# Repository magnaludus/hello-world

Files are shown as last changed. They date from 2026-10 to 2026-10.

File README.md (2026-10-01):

# U1 Breath

A chamber heater and HEPA + activated-carbon filter unit for the **Snapmaker U1**, in the
same class and the same 273 x 175 x 55 mm envelope as the BIQU Panda Breath.

- 300 W 120 V PTC heater, 7530 blower, two 80x80 filter bays (four 80x40x15 HEPA cells plus
  pellet carbon cartridges)
- Own mains power supply; plugs into a wall outlet, works with the printer off
- WiFi web UI, preheat, auto, filament-drying and filter-only modes
- A thermistor stuck under the heated bed turns the unit on and off by itself
  (default: heat when bed >= 90 C, stop below 70 C, filter-only above 45 C)
- Klipper integration with **zero printer-side code**: the firmware speaks the open
  [DragonBreath](https://github.com/plastikman/DragonBreath) REST API, which the
  [paxx12 U1 Extended Firmware](https://github.com/paxx12-snapmaker-u1/SnapmakerU1-Extended-Firmware)
  already drives as a `heater_generic`, so `M141` / `M191` from OrcaSlicer just work
- Mounts inside the chamber on the rear wall, printed in ASA/ABS with M3 heat-set inserts;
  only the heater duct liner is aluminum

## Repository map

| Path | What it is |
|---|---|
| `docs/design.md` | Architecture, airflow, thermal and dimension budgets, safety model |
| `docs/bom.md` | Bill of materials with ratings and example parts |
| `docs/wiring.md` | Wiring diagram, connector pinout, mains safety notes |
| `docs/assembly.md` | Print settings, inserts, step-by-step assembly, liner folding |
| `docs/bringup.md` | First-power checklist, foldback calibration, Klipper enable steps |
| `docs/measurements.md` | The handful of measurements only the owner can take |
| `cad/` | CadQuery parametric model; `python cad/build.py` exports STL, STEP, DXF, SVG |
| `firmware/` | DragonBreath fork with the `u1breath` board profile |
| `klipper/` | Optional macros for the paxx12 `klipper_includes` feature |

## Quick start

1. Read `docs/measurements.md` and fill in `cad/u1breath/params.py`.
2. `pip install cadquery` then `python cad/build.py` to get the printable parts in `cad/out/`.
3. Order the parts in `docs/bom.md`.
4. Build and flash the firmware (`firmware/README.md`), join it to WiFi, give it a static DHCP lease.
5. Assemble (`docs/assembly.md`), then follow `docs/bringup.md` before the first heated print.

## Safety

This project switches 120 V mains inside a printer enclosure. The heater path has three
independent cut-offs (bimetal thermal protector bundled with the PTC element, a one-shot
thermal fuse on the duct liner, and the firmware's latching over-temperature logic), but
the build is only as safe as its wiring. Use the cord, fuse, and crimps specified in the BOM,
keep every mains conductor inside the electronics bay, and never run the heater with the
blower disconnected.

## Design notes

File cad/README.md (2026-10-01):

# U1 Breath CAD

Parametric CadQuery model of the U1 Breath chamber heater + HEPA/carbon filter
unit for the Snapmaker U1.  Overall 172 (X) x 54 (Y) x 273 (Z) mm, three stacked
sections serviced from the front, all plastic parts in ASA with M3 heat-set
inserts, only the heater duct liner in 1 mm aluminium.

## Run

```sh
pip install cadquery pytest          # CadQuery 2.8 or newer
python3 cad/build.py                 # everything, about a minute
python3 cad/build.py mid_body        # one part (STL + STEP only)
python3 -m pytest cad/tests -q       # envelope, build-volume and hot-gap checks
```

Outputs land in `cad/out/` (git-ignored):

| Path | Content |
|---|---|
| `out/stl/<part>.stl`, `out/step/<part>.step` | every part, in its assembled position (bay 0 for the per-bay parts) |
| `out/dxf/heater_liner_flat.dxf` | liner flat pattern, layers `OUTLINE`, `HOLES`, `BEND` |
| `out/layout.svg` | front and side views of the assembly |
| `out/exploded.svg` | exploded isometric view |

Every dimension is a named constant in `cad/u1breath/params.py`; change it there
and rebuild.  Fill in the values from `docs/measurements.md` first (`MOUNT_HOLES`,
`PTC_L/D/H`, `CARBON_MESH_PITCH`).

## Coordinate frame

`Y = 0` is the back face on the printer's rear wall, `+Y` toward the chamber,
`Z = 0` the bottom, air flows up.  The frame is right-handed, so `+X` runs to your
left when you face the unit from inside the chamber (and to the right when the
unit lies on its back, as the parts are printed).  Low X holds the blower, high X
the electronics bay.

## Parts

| Part | Qty | What it is | Print orientation |
|---|---|---|---|
| `back_plate_lower`, `back_plate_upper` | 1 + 1 | 3 mm plate on the rear wall, split at Z 140 with a 10 mm half-thickness lap joint (the full 273 mm plate does not fit the 256 mm bed). Carries the 20 mm mounting grid (4.5 mm, X 10 / 162), six countersunk M4 holes, the M3 clearance holes for the three bodies, the blower's 4 x M4 holes and the standoff bosses for the electronics. | flat, back face (Y = 0) down; the bosses point up |
| `back_plate` | ref. | the same plate in one piece, for printers with a taller bed | flat |
| `filter_bay_body` | 1 | Z 0..110. Two 80 x 80 bay tunnels; from the front: grille, carbon cartridge slot (15), HEPA slot (2 cells 80 x 40 x 15 stacked), retainer frame (3), 12 mm plenum. The plenum fills the whole cavity behind the tunnels and leaves through the 85 x 30 mm roof opening into the blower cavity. | front face (Y = 53) down, open back up; the boss blocks print as columns |
| `intake_grille` | 2 | 3 mm slotted grille (5 mm slots, 2 mm bars), snaps into the bore with two 1 mm nubs; sits 2 mm behind the front face | flat, front down |
| `carbon_cartridge` | 2 | 79.5 x 79.5 x 13 tray with a 2 mm square-mesh back face and two M2 insert bosses; fill with pellet carbon | mesh face down |
| `carbon_cartridge_lid` | 2 | 79.5 x 79.5 x 2 mesh lid, 2 x M2 button screws | flat |
| `hepa_retainer` | 2 | 3 mm open frame with a centre bar between the two cells; goes in first and rests on a 1.5 mm lip at the back of the bore, the HEPA cells drop in after it | flat |
| `mid_body` | 1 | Z 110..195. Sealed blower cavity (low X, fed through the floor opening from the filter plenum; the 7530 lies flat, inlet toward +Y, outlet through the roof opening into the heater shell) and the electronics bay (high X) with four M3 cover bosses and the 12.5 mm PG7 cord-grip hole in the side wall | front face (Y = 48) down, open back up |
| `electronics_cover` | 1 | 3 mm cover with the 10 x 10 LED window and the 8 x 6 JST-XH bed-probe slot; 4 x M3 button screws | flat, front down |
| `heater_shell` | 1 | Z 195..273. ASA box around the liner keeping an 8 mm air gap on every side (2 mm side walls, see below), floor opening above the blower outlet, four bosses behind the front frame for the liner screws | front face (Y = 52) down, open back up |
| `heater_liner` | ref. | folded 1 mm aluminium box (back, top, bottom, two sides; outward 16 mm lips on top and bottom; 10 mm corner tabs) plus the flat slotted front plate 172 x 78 (four rows of 3 x 132 mm slots). Cut both from the DXF. Holes: inlet slot in the bottom wall over the plenum, M3 for the bimetal thermal protector on the top face, M3 for the ring-lug NTC on the high-X side face, 8 mm lead grommet on the low-X side face, four M3 screw holes in the lips and the plate. | not printed |
| `blower_keepout`, `electronics_keepouts`, `ptc_keepout` | ref. | keep-out boxes used by the collision tests | not printed |

Screws: all section bodies screw from behind the back plate into M3 inserts in
the bodies (four per section); the electronics cover and the liner plate screw
from the front.  Inserts: M3 x 5.7 (4.0 mm hole, 6 mm bosses), M2 for the
cartridge lids.  Clearances: 0.3 mm on sliding fits (filters, cartridge,
cover), 0.15 mm on the grille snap nubs.

## Airflow

Grille -> carbon cartridge -> two HEPA cells -> retainer frame -> 12 mm plenum ->
up through the roof opening of the filter bay into the blower cavity -> blower
inlet (+Y face) -> outlet through the mid-body roof and heater-shell floor into
the cold jacket around the liner -> slot in the liner's bottom wall into the 8 mm
plenum behind the PTC -> through the fins toward +Y -> out through the slotted
front plate.  The jacket air keeps the shell cool; the liner never touches plastic.

## Depth budget (Y)

| Section | Stack | Total |
|---|---|---|
| filter bay | 3 plate + 12 plenum + 3 retainer + 15 HEPA + 15 carbon + 3 wall + 2 lip | 53 |
| mid | 3 plate + 30 blower + 12 inlet plenum + 3 wall | 48 |
| heater | 3 plate + 8 gap + 1 liner + 8 plenum + 32 PTC + 1 lips + 1 slotted plate | 54 |

`HEATER_DEPTH` (54) is asserted <= 55 by the tests.

## Tests (`cad/tests/test_envelope.py`)

- every part is a single solid
- the assembled unit is within 273 x 175 x 55 mm (H x W x D) and nothing is behind Y = 0
- every printed part fits a 256 mm cube
- no plastic part intrudes into the liner's inner volume grown by `HOT_GAP` (8 mm) within the heater section
- the PTC, blower and electronics keep-outs collide with nothing

## Design notes / deviations from the brief

- The heater shell's side walls are 2 mm (not 3): 150 mm element + 2 x 1 mm clearance + 2 x 8 mm gap + 2 x 2 mm wall is exactly 172 mm.
- The liner has no printed duct from the blower: the whole shell cavity is the cold-side plenum and the liner takes air through a slot in its bottom wall.  A printed duct would have to touch the liner.
- The slotted outlet is a separate flat plate (second outline in the DXF), screwed through the liner's top/bottom lips into the shell; it adds 1 mm of depth (54 total).  Outlet slots are straight, not angled.
- The HEPA retainer frame adds 3 mm to the filter bay depth (53 instead of 50) because it cannot live inside the 15 mm HEPA slot while the cells fill the full 80 x 80 bore.
- The back plate is printed in two halves with a lap joint.
- The electronics standoff bosses are on the back plate (prints flat), not inside the mid body, so the mid body prints front-face-down without supports.
- The bosses that hold the bodies to the back plate are full-depth columns on the walls (filter bay: blocks in the strips above and below the bay tunnels) so that they print without overhangs; their positions avoid the 20 mm mounting grid.
- `outlet_shroud` was skipped (any trim in front of the plate would exceed the 55 mm depth).

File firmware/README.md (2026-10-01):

# U1 Breath firmware

The firmware is [DragonBreath](https://github.com/plastikman/DragonBreath) with a
`u1breath` board profile (see `UPSTREAM.md` for exactly what differs). You get the
upstream web UI, captive-portal WiFi setup, OTA, Moonraker client, lease/heartbeat
safety model, drying mode, and the paxx12 U1 Extended Firmware integration, plus
the local bed-probe AUTO trigger and the DC blower / WS2812 / 100K NTC hardware.

## Build

Requires ESP-IDF **v5.3.2 or newer** (CI uses v5.3.5). From `firmware/dragonbreath/`:

```bash
. ~/esp/esp-idf/export.sh
idf.py -B build-u1breath \
  -DSDKCONFIG_DEFAULTS="sdkconfig.defaults;sdkconfig.u1breath" build
```

The board is selected by `sdkconfig.u1breath` (`CONFIG_PB_BOARD_U1BREATH=y`). A
plain `idf.py build` still produces the stock Panda Breath image; never flash that
one onto a U1 Breath board.

Optional: copy `main/dev_config.h.example` to `main/dev_config.h` with your WiFi
SSID/password and the printer's Moonraker IP to seed them at first boot. Otherwise
the device starts a `DragonBreath-xxxx` access point and you set them in the portal.

## Flash

The XIAO ESP32-C3's own USB-C port is the flashing and console port (native USB
Serial/JTAG). Hold BOOT while plugging in only if the chip refuses to enter the
bootloader on its own.

```bash
idf.py -B build-u1breath -p /dev/ttyACM0 flash monitor
```

Later updates: use the web UI's firmware update page with
`build-u1breath/dragonbreath.bin` (OTA with automatic rollback if the new image
does not come up healthy).

## First boot

1. Join the `DragonBreath-xxxx` AP, open `http://192.168.4.1`, enter WiFi and the
   printer's Moonraker address. Control source: **Klipper**.
2. Give the unit a **static DHCP lease** on your router. The paxx12 integration
   needs a stable IP.
3. Open `http://<unit-ip>/`. Settings to check on a U1 Breath:

| Setting | Default | Meaning |
|---|---|---|
| `probe_auto` | on | AUTO may heat from the bed probe |
| `probe_on` | 90 C | bed probe at or above this engages heat (in AUTO) |
| `probe_off` | 70 C | bed probe below this releases heat (at least 5 C under `probe_on`) |
| `filter_auto` / `filter_temp` | on / 45 C | blower-only filtration when the bed (probe or printer setpoint) reaches this |
| `max` | 70 C | chamber set-point ceiling (absolute firmware cap, not raisable) |
| `fb_cut` | auto (102 C) | duct-sensor soft foldback; set from bring-up measurements, see `docs/bringup.md` |

The status pixel: dim white idle, green AUTO (slow blink = waiting, solid = heating),
amber manual, blue drying, red blinking = fault latched (clear it from the web UI
or from Klipper with `DRAGONBREATH_RESET`).

BOOT button: tap = arm AUTO / master OFF, hold 2 s = panic-off (latches a fault),
hold 10 s = factory reset (erases WiFi and settings, reboots to the setup AP).

## Modes

- **OFF**: nothing runs except the filtration band and residual-heat purge.
- **AUTO**: heats to the AUTO card target when either the printer reports a filament
  zone through Moonraker (upstream behaviour, blocked while the paxx12 helper is
  installed) or the local bed probe passes `probe_on`. Releases when the probe drops
  below `probe_off`.
- **POWER_ON**: a manual or Klipper-commanded target with a heartbeat lease. Klipper's
  `M141 S0` at the end of a print returns the unit to AUTO if AUTO was armed before.
- **DRYING**: hold a target for N hours (spools on the bed, printer idle).
- **Filter**: blower only, from the web UI, Klipper's `SET_PIN PIN=dragonbreath_filter`,
  or automatically from the filtration band.

## Tests

```bash
cd firmware/dragonbreath
for t in tests/run_*.sh; do sh "$t"; done
```

`tests/run_probe_host_test.sh` compiles the real policy with the U1 Breath board
selected and checks the probe hysteresis, the filtration band, the Klipper OFF
restore, and the single-button mapping. The others are upstream's and must keep
passing in the Panda configuration.

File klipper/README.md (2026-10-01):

# Klipper integration (paxx12 U1 Extended Firmware)

The unit speaks the DragonBreath REST API, which the
[paxx12 U1 Extended Firmware](https://github.com/paxx12-snapmaker-u1/SnapmakerU1-Extended-Firmware)
already supports. No Python, no custom Klipper module.

1. Give the unit a static DHCP lease (its IP must never change between prints).
2. On the printer open `http://<printer-ip>/firmware-config/`, section
   **Snapmaker Components -> PandaBreath / DragonBreath Chamber Heater**, enable
   **DragonBreath**, enter the unit's IP (port 80, token only if you set one in the
   unit's web UI), save. The printer generates
   `extended/klipper/dragonbreath.cfg` with `[dragonbreath] host: <ip>`.
3. Optional: install `u1breath.cfg` from this folder as a custom include for the
   `CHAMBER_PREHEAT`, `CHAMBER_SET`, `CHAMBER_OFF`, `CHAMBER_FILTER` macros.
4. In OrcaSlicer's U1 profile, set the filament's chamber temperature (ABS/ASA 55 C,
   PC 60 C) and make sure the machine start G-code emits `M191` after bed heating,
   for example:

```
M140 S[bed_temperature_initial_layer_single]
M191 S[chamber_temperature]     ; U1 Breath: heat and wait (S0 for PLA/PETG)
```

and the end G-code emits `M141 S0`.

## How the two controllers share the heater

- Klipper's `M141`/`M191` put the unit into a POWER_ON session with a heartbeat
  lease. If Klipper crashes or the printer goes away, the lease expires and the unit
  latches the heater off (default 5 minutes, adjustable 10 s to 5 min).
- The unit's AUTO mode (bed-probe trigger) keeps working underneath: Klipper's
  `M141 S0` at the end of a print returns the unit to AUTO "waiting" instead of OFF,
  so a print that never sends `M141` still gets chamber heat from the bed probe and
  filtration from the filtration band.
- The upstream Moonraker-fed AUTO (filament zone) is disabled while the paxx12
  helper is installed, as upstream intends. The bed probe path is not, because it is
  a physical sensor on the machine.
- `DRAGONBREATH_RESET` clears a latched fault from the printer console.

## Caveat

The paxx12 docs note that chamber heating needs extra U1 mainboard cooling (the
RK3562 throttles at 85 C). This build assumes the mainboard and stepper driver fan
mod is installed. Watch `temperature_sensor` values for the host during the first
heated prints (see `docs/bringup.md`).

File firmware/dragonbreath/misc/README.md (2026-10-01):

# misc

Extras that aren't firmware.

- **`dragonbreath-logo-plaque.3mf`** — a small printable plaque that covers the
  BIQU Panda Breath logo on the device. Print in a **high-heat filament (ABS or
  ASA)** — the device runs warm, so avoid PLA/PETG (they'll creep/sag over time).

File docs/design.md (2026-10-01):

# Design

## What it is

A Panda Breath class unit for the Snapmaker U1: 300 W PTC chamber heater, HEPA +
activated-carbon filtration, its own 120 V supply, WiFi, and a bed probe that lets it
run with no printer connection at all. It fits the Panda Breath envelope
(273 x 175 x 55 mm) and mounts inside the chamber on the rear wall.

The firmware speaks the DragonBreath REST API, which the paxx12 U1 Extended Firmware
already drives as a Klipper `heater_generic`. That decision removed the biggest
chunk of custom work (a Klipper module and a web UI) and bought a proven safety model.

## Layout

Air moves bottom to top. Y = 0 is the back face on the rear wall, +Y faces the chamber.

```
 Z 273 ┌──────────────────────────────────┐
       │  HEATER  ░ 300 W PTC in Al liner ░ │  outlet slots in the liner flange,
       │          blower plenum behind     │  air through the fins toward +Y
 Z 195 ├──────────────────┬───────────────┤
       │  7530 BLOWER     │  ELECTRONICS  │  blower inlet faces +Y inside a sealed
       │  outlet points +Z│  under cover  │  cavity fed from the filter plenum
 Z 110 ├──────────────────┴───────────────┤
       │  BAY 1 80x80     │  BAY 2 80x80  │  grille > carbon cartridge > 2 HEPA cells
       │  carbon | HEPA   │  carbon | HEPA│  > 12 mm plenum, both bays merge upward
 Z 0   └──────────────────────────────────┘
        X 0                            X 172
```

### Depth budget (the tight axis, limit 55 mm)

| Section | Stack (mm) | Total |
|---|---|---|
| Filter bay | back 3 + plenum 12 + retainer 3 + HEPA 15 + carbon 15 + grille 3 + lip 2 | 53 |
| Blower / electronics | back 3 + blower 30 + inlet gap 12 + cover 3 | 48 |
| Heater | back 3 + gap 8 + liner 1 + plenum 8 + element 32 + liner 1 + outlet plate 1 | 54 |

The heater section sets the depth. A 300 W element deeper than 34 mm does not fit;
put the real element dimensions in `cad/u1breath/params.py` and the envelope test
will tell you.

### Why four HEPA cells

HEPA media is restrictive and a 30 mm blower has limited static pressure. Two bays
of two 80 x 40 cells give 128 cm2 of face area, so face velocity at 15 CFM is about
0.55 m/s, which a 7530 blower can push through H11/H13 media. Two cells would need
twice the velocity and a bigger, deeper fan. You have a dozen cells, so spares are free.

### Carbon

Pellet carbon sits in a printed 80 x 80 x 15 mesh cartridge upstream of the HEPA, so
any carbon fines end in the HEPA, not the chamber. About 60 g per cartridge. Change
cartridges every 100 to 150 print hours of ABS/ASA, or when the smell comes back.

## Thermal estimate

Chamber volume of the U1 is roughly 55 L. With the Sterilite tote cover the enclosure
is a thin, leaky box; a workable loss model is UA of about 4 to 5 W/K (cover and
front door glass dominate). At 300 W net and 22 C ambient:

| Loss UA | Steady-state rise | Chamber |
|---|---|---|
| 4 W/K | 75 K (capped by the 70 C setpoint) | 60 C target reached |
| 6 W/K | 50 K | 60 C target reached, slow |
| 8 W/K | 37 K | about 55 C |

The heated bed adds 100 to 150 W of its own at ABS temperatures, which is why the
U1 reaches 50 C passively with the official cover. Expect 60 C in 15 to 25 minutes
with the tote sealed reasonably (foam tape on the tote lip helps more than anything
else). The PTC self-limits: as the air warms its power drops, so the 300 W is a
cold-start number, not a continuous draw.

## Electrical

See `wiring.md` and `wiring.svg`. Summary:

- 120 V: cord > PG7 grip > terminal block > 5 A slow-blow fuse > 10 A zero-cross SSR >
  130 C thermal fuse (on the liner) > 150 C protector (bundled with the element) >
  PTC > neutral. PE bonded to the liner.
- 24 V from an HLK-10M24 runs the blower through a logic-level MOSFET at 25 kHz PWM.
- 5 V from a mini buck runs the XIAO ESP32-C3 and the WS2812.
- Three 100K/3950 NTCs in 100k dividers on the XIAO's three ADC1 pins.

## Firmware

`firmware/dragonbreath` is upstream DragonBreath with a `u1breath` board profile
(`firmware/UPSTREAM.md` lists every difference). Behaviour that matters to the build:

- **Safety layers kept from upstream**: duct sensor hard cutoff 105 C (latching, survives
  reboot), chamber cutoff 85 C, 70 C setpoint cap, fail-closed on any sensor fault
  while heating, comms-loss watchdog (default 5 min) for Klipper/web sessions,
  element foldback (soft cut below the hard trip), fan runs whenever heat runs and
  purges residual heat afterwards.
- **Bed-probe AUTO**: in AUTO mode the probe engages heat at `probe_on` (90 C) and
  releases below `probe_off` (70 C). A dead probe never starts heat. The probe also
  feeds the filtration band (`filter_temp`, 45 C), which runs the blower alone.
- **Klipper**: `M141`/`M191` take over with a heartbeat lease. `M141 S0` hands the
  unit back to AUTO if AUTO was armed, so a print without chamber G-code still
  gets heat from the probe.

## Mechanical and materials

- Shell in ASA or ABS. Nothing printed touches air above about 70 C: the heater
  section has a folded 1 mm aluminum liner with an 8 mm air gap to the shell, and the
  outlet slots are cut in the liner's own flange.
- M3 heat-set inserts in bosses; M2 inserts on the carbon cartridge lids.
- 3 mm silicone foam tape seals the filter grille, the liner flange, and the
  back plate to the rear wall so the blower pulls through the filters, not around them.
- Back plate hole pattern is parametric (`MOUNT_HOLES`) because the U1 rear wall
  has not been measured yet; see `measurements.md`.

## Known compromises

- Every electronic part lives at chamber temperature (60 to 65 C). All are rated
  70 C or better and the SSR is 4x oversized. A through-wall mount would avoid this,
  but you chose inside-chamber for a no-drill install.
- The duct NTC reads the liner wall, not the PTC ceramic. The upstream cutoffs were
  tuned for the Panda's element sensor, so bring-up includes measuring the liner
  temperature and placing the sensor where it reads 80 to 95 C at steady state.
- The Sterilite cover is less sealed than the official Top Cover. If the chamber
  stalls in the low 50s, seal the tote lip before blaming the heater.

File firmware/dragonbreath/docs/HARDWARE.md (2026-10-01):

# Panda Breath V1.0 / V1.0.1 — hardware map

BIGTREETECH Panda Breath control board. Mains-powered PTC chamber heater
+ AC blower fan, controlled over WiFi. Reverse-engineered from the board, the
schematic, and the stock firmware. Reverse-engineered and validated on a **V1.0.1**
board; the **V1.0** board is identical except for the thermistor reference resistor
(33 kΩ vs V1.0.1's 82 kΩ), auto-detected at boot from the Rref strap (GPIO19) and
reported as `rref_kohm` — the V1.0 board is confirmed in the field.

## Core components
| Block | Part | Notes |
|---|---|---|
| MCU | **ESP32-C3-MINI-1-H4X** | RISC-V, 4MB flash, WiFi+BLE |
| USB-UART | **CH340K** | flashing/console path (native USB unusable — see below) |
| PSU | **Hi-Link HLK-PM01** | 100–240 VAC → 5 V 0.6 A → AMS1117-3.3 |
| Heater switch | **MGR GJ-5-L SSR** | 5 A 24–380 VAC, DC-controlled, on/off only |
| Fuse | **jdtfuse T6.3A 250V** | over-current only (NOT over-temp) |
| Fan | **STKJ ST7530B220H** | ~220 VAC EC blower, 0.054 A (~12 W), 2-wire |
| Fan drive | **MOC3021 + BT136-800E** | random-phase opto-triac + TRIAC; hardware supports phase-angle, but DragonBreath drives it **on/off only** (switched at the zero-cross, never phase-chopped) |
| Zero-cross | **MB6S + TLP785 (P785)** | bridge + opto → ZCD pulse to the MCU |

## GPIO map (see `components/pb_board/include/pb_board.h`)
| Function | GPIO | Confidence |
|---|---|---|
| Heater SSR (RLY_MOSFET) | 18 | INFERRED (pad 26) |
| Fan TRIAC gate | 3 | CONFIRMED (IO03) |
| Zero-cross detect | 7 | CONFIRMED (IO07) |
| Chamber NTC (TH0) | 0 / ADC1_CH0 | INFERRED (pad 12) |
| PTC element NTC (TH1) | 1 / ADC1_CH1 | INFERRED (pad 13) |
| Rref divider strap | 19 | reads 82 vs 33 kΩ series resistor |
| Mode LEDs Auto / On / Dry | 6 / 5 / 4 | CONFIRMED |
| Power LED | 21 | CONFIRMED (shared w/ UART0-TX; needs `CONFIG_PB_POWER_LED`) |
| Buttons Power / Auto / On / Dry | 9 / 8 / 10 / 2 | CONFIRMED (bench-probed active-low) |
| Console UART0 TX/RX | 21 / 20 | CONFIRMED |

> **Continuity-test the INFERRED pins before the first flash.** A wrong heater or
> TRIAC pin is a safety issue.

> ⚠️ **Do not hold a front-panel button while powering the board on.** GPIO9
> (Power) is the ROM download-mode strap, and GPIO8 (Auto) and GPIO2 (Dry) are
> also strapping pins that must read HIGH at reset. GPIO10 (On) is the only
> button on a non-strapping pin. Buttons are active-low with internal pull-ups,
> so a held button pulls its strap low at reset and the board will not boot
> normally.

An earlier revision of this table claimed buttons were on GPIO7 and GPIO0,
shared with the zero-cross detector and the chamber NTC. That was **wrong** —
a live bench probe (2026-07-23) placed all four buttons on their own unshared
pins. Each button is co-located with the LED of the same panel label (e.g. Auto
= button GPIO8 / LED GPIO6).

## Flashing path
The ESP32-C3's *native* USB-Serial-JTAG is on GPIO18/19; GPIO18 drives the heater
SSR, so native USB is unavailable. USB flashing (recovery only) goes via the
**CH340K UART bridge** (USB-C → CH340K → UART0) in download mode, using esptool.
As of v1.0.0 DragonBreath ships as an **app in the stock partition layout** —
`partitions.csv` matches the stock Panda Breath layout byte-for-byte (stock
2nd-stage bootloader + partition table are preserved, never modified), so the normal
install/revert path is the stock firmware's own OTA updater with no USB at all.

## Temperature sensing
See [`NTC_CONVERSION.md`](NTC_CONVERSION.md) for the fully reverse-engineered
ADC→temperature conversion (resistance divider + 114-entry R/T lookup table).

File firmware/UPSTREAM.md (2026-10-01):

# Upstream

`firmware/dragonbreath/` is a git subtree of
[plastikman/DragonBreath](https://github.com/plastikman/DragonBreath) (MIT),
squashed at commit `f311a22c39a3e3aef92d10f0f6c3f2d5d63e02b9` (release v1.1.19,
2026-09-23). Its shared services come from
[justinh-rahb/dragon-core](https://github.com/justinh-rahb/dragon-core) v0.35.2
through the ESP-IDF component manager (see `main/idf_component.yml`).

## What this fork changes

Everything U1 Breath-specific is behind the `CONFIG_PB_BOARD_U1BREATH` Kconfig
choice (`components/pb_board/Kconfig`), so the stock Panda Breath build is
unchanged:

| Area | Panda Breath (upstream) | U1 Breath |
|---|---|---|
| Heater SSR | GPIO18 | GPIO6 |
| Fan | 220 V blower, TRIAC on GPIO3, ZCD GPIO7 | 24 V DC blower, LEDC PWM on GPIO7 (`pb_fan_pwm.c`) |
| NTCs | 2, stock R/T table, 82k/33k strap | 3 x 100K/3950 Beta model, fixed 100k (chamber GPIO2, duct GPIO3, bed probe GPIO4) |
| LEDs | 4 panel LEDs | 1 WS2812 on GPIO10 (`pb_leds_ws2812.c`) |
| Buttons | 4 | XIAO BOOT on GPIO9 (short: AUTO/OFF toggle, 2 s: panic-off, 5 s: factory reset) |
| AUTO | printer filament zone via Moonraker | plus a local bed-probe trigger with hysteresis |
| Console | UART0 on GPIO21/20 | native USB Serial/JTAG |
| Extra component | none | `components/led_strip` vendored from idf-extra-components (Apache-2.0) |

## Pulling upstream

```bash
git subtree pull --prefix=firmware/dragonbreath https://github.com/plastikman/DragonBreath.git main --squash
```

Resolve conflicts in the files listed above; everything else should merge clean.

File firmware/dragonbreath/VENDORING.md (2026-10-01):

# Shared-component provenance

DragonBreath consumes its board-neutral services from
[`justinh-rahb/dragon-core`](https://github.com/justinh-rahb/dragon-core) through
ESP-IDF Component Manager. The exact revision is pinned for every component in
[`main/idf_component.yml`](main/idf_component.yml); the source is no longer copied
into DragonBreath's `components/` directory.

## Current shared components

| Component | Origin | Purpose |
|---|---|---|
| `dc_evlog` | OpenVent `pv_evlog` via DragonBreath `pb_evlog` | in-memory event and console rings |
| `dc_wifi` | OpenVent `pv_wifi` via DragonBreath `pb_wifi` | Wi-Fi STA/AP provisioning, scanning, and mDNS |
| `dc_moonraker` | OpenVent `pv_moonraker` via DragonBreath `pb_moonraker` | Moonraker WebSocket client |
| `dc_source` | DragonBreath `pb_source` | persisted control-source selection |
| `dc_bambu` | DragonBreath `pb_bambu` | Bambu LAN MQTT client and printer status |
| `dc_ui` | DragonBreath dashboard SPA | embedded family UI asset and capability gating |
| `dc_mqtt` | DragonBreath HA/Klipper MQTT clients | shared ESP-MQTT session lifecycle and transport callbacks |
| `dc_portal` | DragonBreath provisioning + recovery portal | HTTP server, family SPA, captive DNS, Wi-Fi/AP setup, logs, OTA and reset transport |

DragonBreath retains its product-specific board, sensor, actuator, safety-policy,
HTTP API, portal adapter/schema, LED, button, Home Assistant/Klipper protocol
policy, and HIL components. The `db_portal` adapter supplies product identity,
authorization, safety/OTA validation and persistence callbacks to `dc_portal`.

## OpenVent lineage

The first three components originated in
[`justinh-rahb/OpenVent`](https://github.com/justinh-rahb/OpenVent) at commit
`ec4691f8d7fe95be8e3c6af4cac35d4992b08c79` (`v0.3.0-4-gec4691f`). DragonBreath
initially consumed them through a submodule, then copied them locally in v0.6.1 and
renamed their `pv_*` APIs to `pb_*`. The current extraction moves those copies, plus
the DragonBreath-originated source selector, Bambu client, shared UI, MQTT session
transport, and common provisioning/recovery plane into `dragon-core` and renames
their public APIs to the product-neutral `dc_*` namespace.

`dc_wifi` additionally exposes a product identity API so each consumer supplies its
own hostname, mDNS instance name, and provisioning-AP branding instead of applying
post-start overrides.

## License

OpenVent and dragon-core are MIT licensed. The OpenVent attribution remains part of
this provenance record even though the components have moved repositories and their
symbols have changed. See each upstream repository's `LICENSE` file for the license
text.

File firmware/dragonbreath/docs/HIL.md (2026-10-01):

# Hardware-in-the-loop testing

DragonBreath HIL runs the production policy state machine on either a GPIO-safe
ESP32-C3 development board or a real Panda Breath. `tools/hil.py` builds the
selected profile, optionally flashes it, drives line-delimited JSON commands,
captures the complete serial console, evaluates scripted assertions, and writes
a machine-readable report.

## Qualification status

As of 2026-07-23:

- The complete devboard suite passes on a dual-USB-C ESP32-C3 board through its
  CH341-family UART bridge.
- Both devboard transports pass the compile-time GPIO/ADC exclusion audit.
- The native-USB image builds and flashes, but this board's application-side
  native USB serial endpoint did not respond during qualification.
- The real-Panda UART profile passes the non-heating smoke scenario on physical
  hardware, both as a guarded build/flash run and as an already-flashed run.

## Safety boundaries

The two HIL targets intentionally have different hardware behavior.

### Devboard target

`CONFIG_PB_HIL_DEVBOARD` replaces or removes every Panda-specific physical
backend used by the test path:

- relay output
- fan TRIAC gate and zero-cross GPIO
- chamber and PTC ADC
- Panda indicator LEDs
- board-strap input

Heater demand, heater output, fan percentage, LED patterns, and zero-cross
diagnostics still update as logical state. Every response identifies this target
with:

```json
{
  "state": {
    "io": {
      "target": "devboard",
      "mains_gpio_compiled_out": true
    }
  }
}
```

`tests/check_hil_compileout.sh` inspects the built component archives and fails
if a devboard backend references the excluded GPIO or ADC APIs.

### Real-Panda target

The Panda profile uses real sensors and actuators. The runner provides two
independent host-side acknowledgements:

- `--allow-panda-flash` authorizes replacing firmware on a real unit.
- `--allow-heater` authorizes positive-target `power_on`, `auto`, or `drying`
  commands.

These checks protect runner-driven workflows; they are not authentication in
the firmware protocol. A different serial writer can send commands directly.
Real-unit HIL must therefore be supervised with the normal electrical and
thermal precautions.

The Panda power LED must remain disabled in this profile. GPIO21 is both the
optional power LED and UART0 TX:

```text
# CONFIG_PB_POWER_LED is not set
CONFIG_ESP_CONSOLE_UART_DEFAULT=y
```

## Profiles

| Target | Transport | Overlay | Typical port | Physical I/O |
|---|---|---|---|---|
| Devboard | Native USB Serial/JTAG | `sdkconfig.hil-devboard` | `/dev/ttyACM0` | Panda I/O compiled out |
| Devboard | USB-to-UART bridge | `sdkconfig.hil-devboard-uart` | `/dev/ttyUSB0` | Panda I/O compiled out |
| Panda | On-board UART bridge | `sdkconfig.hil-panda` | `/dev/ttyUSB0` | Real hardware active |

## Native-USB production-network debugging

`sdkconfig.debug-devboard-native` is a non-HIL debug profile for a generic
ESP32-C3 development board. It runs DragonBreath's production networking, portal,
dashboard, and control-source clients with normal ESP-IDF logs on native USB
Serial/JTAG. Panda-specific relay, fan, ADC, LED, button, and strap backends are
compiled out, so GPIO18/19 remain available to USB and the image cannot drive
Panda mains hardware. The HIL JSON command console is disabled.

Build, audit, flash, and monitor it with:

```bash
source ~/esp/esp-idf/export.sh
idf.py -B build-debug-devboard-native \
  -DSDKCONFIG="$PWD/build-debug-devboard-native/sdkconfig.profile" \
  -DSDKCONFIG_DEFAULTS="sdkconfig.defaults;sdkconfig.debug-devboard-native" \
  build
sh tests/check_devboard_compileout.sh build-debug-devboard-native
idf.py -B build-debug-devboard-native -p /dev/ttyACM0 flash monitor
```

This profile is for development boards only. Do not flash it onto a Panda Breath:
its physical sensors, buttons, LEDs, fan, and heater are intentionally unavailable.

When `--transport` is omitted, the runner infers `native` from `/dev/ttyACM*`
and `uart` from `/dev/ttyUSB*`. Pass it explicitly for other device naming
schemes.

Each profile uses a separate generated `sdkconfig.profile` inside its build
directory. This prevents HIL symbols or console choices from leaking into the
normal firmware build.

## Prerequisites

On the build machine:

- this repository
- ESP-IDF 5.3
- Python from the ESP-IDF environment
- `pyserial` for local serial I/O
- `ssh` and `scp` for remote operation

On a remote device host:

- SSH access
- Python 3.9 or newer
- `pyserial`
- an esptool installation when using `--flash`
- permission to open the serial device, normally through the `dialout` group

Activate ESP-IDF before a build or any `--flash` invocation:

```bash
source ~/esp/esp-idf/export.sh
idf.py --version
python -c 'import serial; print(serial.__version__)'
```

## Local operation

Run all scenarios compatible with a bridge-connected devboard:

```bash
python tools/hil.py \
  --target devboard \
  --port /dev/ttyUSB0 \
  --flash \
  --suite
```

Run one scenario without rebuilding or flashing:

```bash
python tools/hil.py \
  --target devboard \
  --port /dev/ttyUSB0 \
  --scenario tests/hil/scenarios/devboard-safety.json
```

Use native USB explicitly:

```bash
python tools/hil.py \
  --target devboard \
  --transport native \
  --port /dev/ttyACM0 \
  --flash \
  --suite
```

Drive the console interactively by entering one JSON object per line:

```bash
python tools/hil.py \
  --target devboard \
  --port /dev/ttyUSB0 \
  --interactive
```

Example interactive input:

```json
{"cmd":"sensor","channel":"chamber","status":"ok","temp_c":25}
{"cmd":"sensor","channel":"ptc","status":"ok","temp_c":25}
{"cmd":"mode","mode":"power_on","target_c":50}
{"cmd":"state"}
{"cmd":"off"}
```

## Remote device-host operation

Use `--host` when ESP-IDF and the repository are on the workstation but the
serial device is attached to another machine. The runner:

1. builds locally when `--flash` is present;
2. reads ESP-IDF's generated `flasher_args.json`;
3. creates an isolated directory on the remote host;
4. transfers the exact flash images, runner, and scenarios;
5. flashes and runs beside the serial device;
6. copies `report.json` and `serial.jsonl` back to the local output directory.

For a bridge-connected board on a Linux device host:

```bash
python tools/hil.py \
  --host tester@hil-host \
  --target devboard \
  --port /dev/ttyUSB0 \
  --remote-esptool /home/tester/hil-tools/.venv/bin/esptool.py \
  --flash \
  --suite \
  --verbose
```

To rerun the suite against the already-flashed firmware:

```bash
python tools/hil.py \
  --host tester@hil-host \
  --target devboard \
  --port /dev/ttyUSB0 \
  --suite
```

Useful remote options:

| Option | Default | Purpose |
|---|---|---|
| `--remote-python` | `python3` | Python interpreter containing `pyserial` |
| `--remote-esptool` | `esptool.py` | Remote esptool executable |
| `--remote-dir` | `/tmp/dragonbreath-hil` | Remote staging root |
| `--flash-baud` | `460800` | Esptool transfer baud |
| `--output-dir` | timestamped `hil-results/` | Local report destination |

Remote operation requires an explicit `--port`; local auto-detection is not
used for a different machine.

## Real-Panda qualification

Run the non-heating smoke scenario against an already-flashed unit:

```bash
python tools/hil.py \
  --host tester@hil-host \
  --target panda \
  --port /dev/ttyUSB0 \
  --scenario tests/hil/scenarios/panda-smoke.json
```

Authorize a real-unit flash separately:

```bash
python tools/hil.py \
  --host tester@hil-host \
  --target panda \
  --port /dev/ttyUSB0 \
  --remote-esptool /home/tester/hil-tools/.venv/bin/esptool.py \
  --flash \
  --allow-panda-flash \
  --scenario tests/hil/scenarios/panda-smoke.json
```

Add `--allow-heater` only for a supervised scenario that intentionally requests
a positive temperature. The provided Panda smoke scenario never requests heat.

### Reference hardware result

The real-Panda workflow was qualified on 2026-07-23 using commit `7883dda`, an
ESP32-C3 revision 1.1 Panda connected to a generic Linux SSH device host through
its on-board QinHeng `1a86:7522` UART bridge, and ESP-IDF 5.3.1 on the build
machine.

Before flashing, the complete 4 MiB device flash was read and its local and
remote SHA-256 digests were compared. The guarded run then:

1. built the `sdkconfig.hil-panda` profile;
2. transferred the manifest and images to the device host;
3. flashed and reset the Panda with remote esptool;
4. ran `panda-smoke.json`; and
5. retrieved `report.json` and `serial.jsonl`.

The same scenario passed again without `--flash`, proving the normal attach and
test path against an already-running unit. Both runs reported:

- `target: "panda"` over the `uart` transport;
- `mains_gpio_compiled_out: false`, confirming the real hardware profile;
- valid chamber/PTC readings and live zero-cross counts;
- successful `state` and unconditional `off` commands; and
- final mode `off` with `heater_demand: false` and `heater_output: false`.

The build profile contained `CONFIG_PB_HIL_CONSOLE=y`,
`CONFIG_ESP_CONSOLE_UART_DEFAULT=y`, and no `CONFIG_PB_POWER_LED`. Neither run
used `--allow-heater`, so the harness could not issue a positive heat request.

## Manual builds

The runner performs these isolated builds when `--flash` is supplied. They can
also be run directly:

```bash
idf.py -B build-hil-devboard \
  -DSDKCONFIG="$PWD/build-hil-devboard/sdkconfig.profile" \
  -DSDKCONFIG_DEFAULTS="sdkconfig.defaults;sdkconfig.hil-devboard" \
  build

idf.py -B build-hil-devboard-uart \
  -DSDKCONFIG="$PWD/build-hil-devboard-uart/sdkconfig.profile" \
  -DSDKCONFIG_DEFAULTS="sdkconfig.defaults;sdkconfig.hil-devboard-uart" \
  build

idf.py -B build-hil-panda \
  -DSDKCONFIG="$PWD/build-hil-panda/sdkconfig.profile" \
  -DSDKCONFIG_DEFAULTS="sdkconfig.defaults;sdkconfig.hil-panda" \
  build
```

Audit either devboard build:

```bash
sh tests/check_hil_compileout.sh build-hil-devboard
sh tests/check_hil_compileout.sh build-hil-devboard-uart
```

## Scenario format

Scenarios are JSON objects stored under `tests/hil/scenarios/`:

```json
{
  "name": "example",
  "targets": ["devboard"],
  "steps": [
    {
      "name": "inject a nominal sensor",
      "send": {
        "cmd": "sensor",
        "channel": "chamber",
        "status": "ok",
        "temp_c": 25
      },
      "expect": {
        "ok": true,
        "state.sensors.chamber.status": "ok"
      }
    },
    {
      "name": "request heat and save the lease",
      "send": {"cmd": "mode", "mode": "power_on", "target_c": 50},
      "save": {"lease": "lease_id"}
    },
    {"name": "allow one control tick", "wait_s": 0.7},
    {
      "name": "renew ownership",
      "send": {"cmd": "heartbeat", "lease_id": "$lease"},
      "expect": {"ok": true, "state.lease_active": true}
    }
  ]
}
```

Step fields:

| Field | Meaning |
|---|---|
| `name` | Human-readable step label |
| `send` | JSON request object; the runner adds `id` |
| `wait_s` | Delay-only step, mutually exclusive with `send` |
| `timeout_s` | Response timeout override, default 4 seconds |
| `expect` | Dotted response paths and expected values |
| `save` | Variable name to dotted response path |

A string beginning with `$` substitutes a saved variable recursively in later
requests. Assertions accept exact values or one operator:

```json
{
  "state.io.zero_cross_count": {"gte": 12},
  "state.mode": {"ne": "drying"},
  "state.fault_reason": {"contains": "sensor"}
}
```

Supported operators are `eq`, `ne`, `gt`, `gte`, `lt`, `lte`, and `contains`.
`--suite` loads only scenarios whose `targets` include the selected target.

## Serial protocol

Requests are one UTF-8 JSON object per line. Firmware emits exactly one
correlated response prefixed with `DBHIL `:

```text
{"cmd":"state","id":7}
DBHIL {"id":7,"ok":true,"state":{...}}
```

Other serial lines are treated as ordinary ESP-IDF console logs and retained in
the transcript.

Commands available on both targets:

| Command | Required fields | Effect |
|---|---|---|
| `ping` | none | Return current state |
| `state` | none | Return current state |
| `off` | none | Request authoritative OFF |
| `mode` | `mode` and mode-specific values | Select `off`, `power_on`, `auto`, or `drying` |
| `heartbeat` | `lease_id` | Renew active remote ownership |
| `clear_fault` | none | Clear a recoverable fault and remain OFF |

Devboard-only injection:

| Command | Fields | Effect |
|---|---|---|
| `sensor` | `channel`, `status`, optional `temp_c` | Inject chamber/PTC value or `open`, `short`, `uninit` |
| `env` | `connected`, `bed_c` | Inject Moonraker connection and bed temperature |
| `zero_cross` | optional `count`, `interval_us` | Inject fan zero-cross diagnostics |
| `button` | `button`, `level` | Inject a raw level (`0` pressed, `1` released) for `power`, `auto`, `on`, or `dry` |

Every response includes the authoritative policy snapshot: mode, source,
revision, targets, heater demand/output, fan percentage, fault/inhibit state,
lease state, sensors, printer environment, logical LEDs, target identity, and
zero-cross diagnostics.

## Results

Each scripted run writes:

- `report.json`: target, transport, port, overall result, scenario results,
  per-step duration, response snapshots, and failures.
- `serial.jsonl`: timestamped `tx` and `rx` records containing every command,
  response, and console log line.

The default local location is `hil-results/YYYYMMDD-HHMMSS/`. This directory is
gitignored. With `--host`, results are generated remotely and then copied to the
same local structure. The downloaded report records the SSH host and rewrites
its transcript path to the local copy. Missing remote artifacts fail the run
instead of being ignored.

## CI coverage

The firmware workflow:

- runs the policy, API, dashboard, and HIL runner tests;
- builds normal firmware with ESP-IDF 5.3;
- builds native-USB and UART devboard HIL images;
- runs the compile-out audit against both images;
- uploads both devboard application binaries.

Physical HIL remains a deliberate lab qualification rather than a GitHub-hosted
runner job.

## Troubleshooting

### No serial device

Inspect USB enumeration and persistent names:

```bash
lsusb
ls -l /dev/serial/by-id
ls -l /dev/ttyACM* /dev/ttyUSB*
dmesg --ctime | tail -30
```

Native ESP USB normally appears as `/dev/ttyACM*`; CH341/CH340 bridges normally
appear as `/dev/ttyUSB*`.

### Permission denied

Check the device group and current memberships:

```bash
ls -l /dev/ttyUSB0
id
```

Add the device-host user to `dialout`, then start a new login session.

### Port opens but requests time out

- Confirm the firmware transport matches the connector.
- Confirm no monitor or other process owns the port with
  `fuser -v /dev/ttyUSB0`.
- Reset the board and inspect the captured ESP-IDF logs.
- If using native USB, try the bridge/UART profile; native application serial
  remains unqualified on the current dual-USB-C board.

The runner explicitly releases DTR/RTS after opening the port and bounds serial
writes so an unresponsive native USB endpoint cannot wedge the test process.

### Board remains in the ROM loader

Use the connector matching the selected profile and reset without holding BOOT.
For remote flashing, verify that `--remote-esptool` names the intended
installation and that the user can open the selected port.

### Wrong configuration appears in a build

Do not share the repository-root generated `sdkconfig` between profiles. Use the
documented `-DSDKCONFIG=.../sdkconfig.profile` commands or let the runner select
the isolated build directory.

### Real Panda UART output is missing

Verify `CONFIG_PB_POWER_LED` is disabled. Enabling it claims GPIO21 and conflicts
with UART0 TX.

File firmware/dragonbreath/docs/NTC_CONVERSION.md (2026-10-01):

# Panda Breath (ESP32-C3) — NTC ADC→Temperature conversion, fully reversed

> **⚠️ HARDWARE CORRECTION (2026-07-21).** This report's `Vrail = 0.1 V` divider
> constant is **wrong**. On real hardware the ADC pin sits ~1.6 V at ambient, so
> the constant `K` in `Rntc = Rref·V/(K−V)` is the **~3.3 V supply**, not 0.1 V.
> The report's *formula shape*, the 82/33 kΩ `Rref` strap, and the R/T table are
> all correct — only the constant was misidentified. Validated on device: with
> `K = 3.3 V` the chamber NTC read **33.0 °C**, matching the printer's extruder
> thermistors (33.0 °C) exactly. The firmware uses `PB_NTC_VSUPPLY_V = 3.3f`
> (`components/pb_ntc/include/pb_ntc.h`). **The formulas and reproduction configs
> below have been updated to `3.3 V`; the original `0.1 V` DROM finding is retained
> only as a decompile note.**

Target: chamber NTC (GPIO0 / ADC1_CH0) and PTC-element NTC (GPIO1 / ADC1_CH1).
Both channels use the **identical** conversion. All float math is soft-float ROM
libgcc (`__mulsf3`, `__subsf3`, `__divsf3`, `__floatsisf`, `__fixunssfsi`), verified
against `esp32c3.rom.libgcc.ld` with the −8 address correction applied to every
absolute ROM target.

---

## 1. The exact formula

```
V      = ADC pin voltage, in VOLTS   (calibrated: adc_oneshot_read -> adc_cali_raw_to_voltage / 1000)
Rref   = 82.0  (kOhm)   [board variant A, GPIO19 = 0]   OR   33.0 (kOhm) [variant B, GPIO19 = 1]
Vsupply = 3.3  (V)      [divider top rail — see the HARDWARE CORRECTION above.
                        A DROM const 0.1 V @0x3c0e681c=0x3dcccccd was the ORIGINAL
                        (wrong) identification; real hardware needs 3.3 V.]

Rntc_kOhm = Rref * V / (Vsupply - V)         <-- low-side NTC divider, solved for Rntc

temp_C    = table_lookup(Rntc_kOhm)         <-- nearest entry in the R/T table, returns temp
temp_out  = mean of the last <=5 successive temp_C readings   (5-sample moving average)
```

`temp_out` is finally converted to an unsigned byte (`__fixunssfsi`, i.e. truncation)
and stored to `*0x3fc9ca80` (chamber) or `*0x3fc9ca81` (PTC, when mode `*0x3fc9ca78 == 1`).

### Register-level proof (fcn.4200cbf4, one loop iteration)

```
lw   a0, *0x3fc9ca7c          ; a0 = Rref  (int 82 or 33)
call 0x40000808 (−8 = 0x40000800 __floatsisf)   ; s1 = (float)Rref
lw   a0, 8(sp)                ; a0 = V_mV  (adc_cali output, integer mV)   ** see §4 units note
call 0x40000808 __floatsisf                       ; s0 = (float)V
call 0x4000085c (−8 = 0x40000854 __mulsf3)  (Rref, V)     ; s1 = Rref * V
lw   a0, *0x3c0e681c          ; a0 = 0.1
call 0x400008a0 (−8 = 0x40000898 __subsf3)  (0.1, V)      ; a0 = 0.1 − V
call 0x400007c4 (−8 = 0x400007bc __divsf3)  (Rref*V, 0.1−V) ; a0 = Rref*V/(0.1−V) = Rntc
call 0x4200c922               ; index = binary_search(Rntc)   over table @0x3c0e6638
addi a0, a0, 10               ; temp_C = index + 10
call 0x40000808 __floatsisf                       ; (float)temp_C
call 0x4200c9d6               ; push to 5-sample ring, returns running mean in a0
```
After 5 iterations the last returned mean (a0) is truncated with `__fixunssfsi`
(shown 0x400007f8, −8 = 0x400007f0) and written to the temp byte.

The `−8` correction was decisive: the divide/subtract/multiply targets are only one
`.ld` slot apart, so a wrong ±8 flips e.g. `__subsf3`↔`__mulsf3` and inverts the formula.
Every target above was checked against `esp32c3.rom.libgcc.ld`:
`__divsf3=0x400007bc, __mulsf3=0x40000854, __subsf3=0x40000898, __floatsisf=0x40000800,
__fixunssfsi=0x400007f0`.

---

## 2. The divider model

Low-side NTC (thermistor from ADC node to GND, series resistor `Rref` from the rail to
the node), rearranged to give the thermistor resistance:

```
Rntc = Rref * V / (Vrail − V)
```

* `Rref` = **82 kOhm** (or 33 kOhm) — the fixed series resistor, in kOhm. Selected at
  boot by reading **GPIO19** (`fcn.4200cb32` → `gpio_get_level(19)`): level 0 → 82, level 1 → 33.
  This is a hardware-population strap; the 70 °C Panda Breath most likely reads **82 kOhm**
  (confirm empirically: the Rref that yields a sane room-temperature reading is correct).
* `Vsupply` = **3.3 V** (the divider top rail). **⚠️ SUPERSEDED MODEL BELOW:** this
  report originally read the rail as `Vrail = 0.1 V` and explained it with a ~33:1 ADC
  input-scaling theory (pin swings ~0–95 mV). That was **disproven on hardware** (see
  the HARDWARE CORRECTION at the top): the pin sits ~1.6 V at ambient and the operative
  constant is the **3.3 V** supply — there is no 33:1 scaling. Use `Vsupply = 3.3 V`.
  **What matters for reproduction: `V` and `Vsupply` share units (volts) and `V` is the
  actual calibrated pin voltage.**
* The table (`Rntc`) is in **kOhm**, so `Rref` must be in **kOhm** (82, not 82000).

The thermistor is a ~100 kOhm NTC (table: 100 kOhm at 27 °C, ~109 kOhm at 25 °C,
doubling roughly every 15 °C — a standard R/T curve). The firmware uses a **lookup
table with nearest-entry selection**, NOT a beta/Steinhart log formula (confirmed: no
`logf/expf/powf/libm` anywhere in the image).

---

## 3. The R/T table (DROM @ 0x3c0e6638, little-endian float32)

`temp_C = index + 10`. Index 0 (10 °C) and index 1 (11 °C) hold garbage
(7.4e31 and 0.0) and are never reached for valid readings; usable range is index 2..115+
(12 °C .. 125 °C+). Binary search upper bound is 0x73 = 115; entries beyond 114 exist
(idx115 = 3.4 kOhm) so the search never reads out of bounds.

```
temp_C : Rntc(kOhm)
 12:198.7  13:189.4  14:180.7  15:172.4  16:164.5  17:157.0  18:149.9  19:143.2
 20:136.8  21:130.7  22:124.9  23:119.4  24:114.2  25:109.2  26:104.5  27:100.0
 28: 95.7  29: 91.6  30: 87.8  31: 84.1  32: 80.6  33: 77.2  34: 74.0  35: 70.9
 36: 68.0  37: 65.3  38: 62.6  39: 60.1  40: 57.7  41: 55.4  42: 53.2  43: 51.1
 44: 49.1  45: 47.2  46: 45.3  47: 43.6  48: 41.9  49: 40.3  50: 38.8  51: 37.3
 52: 35.9  53: 34.5  54: 33.2  55: 32.0  56: 30.8  57: 29.7  58: 28.6  59: 27.6
 60: 26.6  61: 25.6  62: 24.7  63: 23.8  64: 23.0  65: 22.2  66: 21.4  67: 20.6
 68: 19.9  69: 19.2  70: 18.6  71: 17.9  72: 17.3  73: 16.7  74: 16.2  75: 15.6
 76: 15.1  77: 14.6  78: 14.1  79: 13.6  80: 13.2  81: 12.8  82: 12.4  83: 12.0
 84: 11.6  85: 11.2  86: 10.9  87: 10.5  88: 10.2  89:  9.9  90:  9.6  91:  9.3
 92:  9.0  93:  8.7  94:  8.4  95:  8.2  96:  7.9  97:  7.7  98:  7.4  99:  7.2
100:  7.0 101:  6.8 102:  6.6 103:  6.4 104:  6.2 105:  6.0 106:  5.9 107:  5.7
108:  5.5 109:  5.4 110:  5.2 111:  5.1 112:  4.9 113:  4.8 114:  4.7 115:  4.5
116:  4.4 117:  4.3 118:  4.2 119:  4.1 120:  3.9 121:  3.8 122:  3.7 123:  3.6
124:  3.5 125:  3.4
```

Binary-search behaviour (`fcn.4200c922`): finds the two bracketing entries and returns
the index of the one with the smaller `|table[i] − Rntc|` — i.e. **nearest neighbour**,
1 °C granularity. (A smooth interpolation, as in the ESPHome lambda below, is strictly
better than the firmware and still matches to <1 °C.)

DROM float constants block @0x3c0e6808 (for reference; the conversion only uses 0.1):
`3.3, 3.2, 0.2, 1.0, 0.01, 0.1(@681c), 2.0, 3300.0`. The 3.3/3.2/0.2/1.0/0.01 values are
loaded by the init into a per-channel struct (`0x3fc96b84`, 60-byte stride) and belong to
a separate EMA/limits path — they are **not** part of the ADC→temp math. `3300.0` is
unused by this conversion.

---

## 4. `*0x3fc9ca7c` and the input units

* `*0x3fc9ca7c` = **Rref** (the series resistor coefficient), an integer written once at
  boot in `fcn.4200cb32`: `82` if `gpio_get_level(19)==0`, else `33`. It is NOT a Vref or
  an ADC count.
* `*0x3fc9ca82` = raw-range fault flag from `fcn.4200ca8e`: raw>0xFFD → 2 (open/over-range),
  raw>0x14 → 0 (ok), else → 1 (short/under-range).
* `*0x3fc9ca88` = adc_oneshot handle, `*0x3fc9ca90` = adc_cali (curve-fit) handle,
  `*0x3fc9ca78` = mode (1 ⇒ PTC channel → stores to ca81).

**Units note (the one subtlety):** `adc_cali_raw_to_voltage` returns integer **mV**, yet
the math requires `V < 0.1`, i.e. `V` in **volts**. The only unit assignment that yields a
monotonic, sane temperature curve (verified by full IEEE-754 simulation of the exact ROM
ops, §5) is `V` in volts. The net firmware behaviour is `Rntc = 82 * V / (0.1 − V)` with
`V` = the true calibrated pin voltage in volts (pin swings ~4–95 mV). For an ESPHome
rebuild that reads the *same pin* with calibration enabled, ESPHome's ADC voltage (volts)
equals the firmware's `V` directly, so the reproduction is faithful regardless of the
internal mV/scale bookkeeping.

---

## 5. Sanity check (exact ROM-op simulation, Rref = 82 kOhm, Vrail = 0.1 V)

```
V = 0.0068 V (6.8 mV)  -> Rntc =  6.0 kOhm -> 105 C   (matches PTC over-temp trip region)
V = 0.0281 V (28 mV)   -> Rntc = 32.0 kOhm ->  55 C
V = 0.0549 V (55 mV)   -> Rntc = 99.8 kOhm ->  27 C   (room temp)
V = 0.0604 V (60 mV)   -> Rntc =124.9 kOhm ->  22 C   (room temp)
V = 0.0041 V ( 4 mV)   -> Rntc =  3.5 kOhm -> 124 C   (top of scale)
```
Room-temperature voltages land at ~20–27 °C and the low-resistance end at the ~105 °C
over-temp region — both physically correct.

---

## 6. ESPHome config

### 6a. Recommended — one `adc` + a `lambda` that reproduces the firmware math exactly

Reads the pin voltage in volts, applies `Rntc = Rref*V/(0.1−V)`, then linear-interpolates
the firmware R/T table. Duplicate the block for GPIO1 (PTC). Set `RREF` to 82.0 or 33.0 to
match your board's GPIO19 strap.

```yaml
sensor:
  # ---------- CHAMBER NTC (GPIO0 / ADC1_CH0) ----------
  - platform: adc
    pin: GPIO0
    name: "Chamber ADC volts"
    id: chamber_adc_v
    attenuation: 0db          # pin swings ~0-95 mV; 0dB (0-950 mV) gives best resolution
    update_interval: 1s
    internal: true            # raw voltage is intermediate

  - platform: template
    name: "Chamber Temperature"
    id: chamber_temp
    unit_of_measurement: "°C"
    accuracy_decimals: 1
    update_interval: 1s
    lambda: |-
      const float RREF    = 82.0f;   // kOhm  (82 if GPIO19=0, else 33)
      const float VSUPPLY = 3.3f;    // V  (divider top rail — see HARDWARE CORRECTION)
      float v = id(chamber_adc_v).state;               // volts at the pin
      if (isnan(v) || v <= 0.0f || v >= VSUPPLY) return NAN;
      float R = RREF * v / (VSUPPLY - v);              // Rntc in kOhm
      // firmware R/T table {temp_C, R_kOhm}, R decreasing with temp
      static const float RT[][2] = {
        {12,198.7f},{13,189.4f},{14,180.7f},{15,172.4f},{16,164.5f},{17,157.0f},
        {18,149.9f},{19,143.2f},{20,136.8f},{21,130.7f},{22,124.9f},{23,119.4f},
        {24,114.2f},{25,109.2f},{26,104.5f},{27,100.0f},{28,95.7f},{29,91.6f},
        {30,87.8f},{31,84.1f},{32,80.6f},{33,77.2f},{34,74.0f},{35,70.9f},
        {36,68.0f},{37,65.3f},{38,62.6f},{39,60.1f},{40,57.7f},{41,55.4f},
        {42,53.2f},{43,51.1f},{44,49.1f},{45,47.2f},{46,45.3f},{47,43.6f},
        {48,41.9f},{49,40.3f},{50,38.8f},{51,37.3f},{52,35.9f},{53,34.5f},
        {54,33.2f},{55,32.0f},{56,30.8f},{57,29.7f},{58,28.6f},{59,27.6f},
        {60,26.6f},{61,25.6f},{62,24.7f},{63,23.8f},{64,23.0f},{65,22.2f},
        {66,21.4f},{67,20.6f},{68,19.9f},{69,19.2f},{70,18.6f},{71,17.9f},
        {72,17.3f},{73,16.7f},{74,16.2f},{75,15.6f},{76,15.1f},{77,14.6f},
        {78,14.1f},{79,13.6f},{80,13.2f},{81,12.8f},{82,12.4f},{83,12.0f},
        {84,11.6f},{85,11.2f},{86,10.9f},{87,10.5f},{88,10.2f},{89,9.9f},
        {90,9.6f},{91,9.3f},{92,9.0f},{93,8.7f},{94,8.4f},{95,8.2f},
        {96,7.9f},{97,7.7f},{98,7.4f},{99,7.2f},{100,7.0f},{101,6.8f},
        {102,6.6f},{103,6.4f},{104,6.2f},{105,6.0f},{106,5.9f},{107,5.7f},
        {108,5.5f},{109,5.4f},{110,5.2f},{111,5.1f},{112,4.9f},{113,4.8f},
        {114,4.7f},{115,4.5f},{116,4.4f},{117,4.3f},{118,4.2f},{119,4.1f},
        {120,3.9f},{121,3.8f},{122,3.7f},{123,3.6f},{124,3.5f},{125,3.4f},
      };
      const int N = sizeof(RT)/sizeof(RT[0]);
      if (R >= RT[0][1])       return RT[0][0];         // clamp cold end (12 C)
      if (R <= RT[N-1][1])     return RT[N-1][0];       // clamp hot end  (125 C)
      for (int i = 0; i < N-1; i++) {
        float rhi = RT[i][1], rlo = RT[i+1][1];         // rhi > rlo
        if (R <= rhi && R >= rlo) {
          float f = (rhi - R) / (rhi - rlo);            // linear interp (0..1)
          return RT[i][0] + f * (RT[i+1][0] - RT[i][0]);
        }
      }
      return NAN;
    filters:
      - sliding_window_moving_average:      # mirrors the firmware 5-sample mean
          window_size: 5
          send_every: 1
```

For the **PTC channel**, copy both sensors with `pin: GPIO1`, ids `ptc_adc_v` /
`ptc_temp`, and reference `id(ptc_adc_v)` in the lambda. Same `RREF`, same table.

For **bit-exact** parity with the firmware (nearest-entry, integer °C) replace the
interpolation loop with a nearest-neighbour pick and `return roundf(...)`; the interpolated
version above is smoother and within <1 °C of the firmware everywhere.

### 6b. Alternative — stock `adc` + `resistance` + `ntc` platforms

`resistance` in **DOWNSTREAM** mode computes exactly `R = resistor * V/(reference_voltage − V)`,
which is the firmware formula. Then `ntc` fits a Steinhart-Hart curve through table points.
This is cleaner but approximates the table (still <~0.5 °C error since the table is itself a
smooth NTC curve).

```yaml
sensor:
  - platform: adc
    pin: GPIO0
    id: chamber_adc_v
    attenuation: 0db
    update_interval: 1s
    internal: true

  - platform: resistance
    sensor: chamber_adc_v
    id: chamber_ntc_r
    configuration: DOWNSTREAM
    resistor: 82kOhm            # = Rref  (33kOhm for GPIO19=1 boards)
    reference_voltage: 3.3V     # = Vsupply (see HARDWARE CORRECTION; NOT 0.1V)
    internal: true
    # NOTE: the ADC source above must use full-range attenuation (e.g. attenuation:
    # 12db) — the real pin sits ~1.6 V at ambient, not the ~0.1 V the superseded
    # 33:1-scaling model assumed. Cross-check against the firmware (components/pb_ntc).

  - platform: ntc
    sensor: chamber_ntc_r
    name: "Chamber Temperature"
    unit_of_measurement: "°C"
    calibration:
      - 109.2kOhm -> 25°C       # table idx15
      - 18.6kOhm  -> 70°C       # table idx60
      - 6.0kOhm   -> 105°C      # table idx95
    filters:
      - sliding_window_moving_average: { window_size: 5, send_every: 1 }
```
(Repeat for GPIO1/PTC with its own `resistance` + `ntc` pair.)

---

## 7. Confidence & unresolved items

**High confidence:**
* Formula `Rntc = Rref * V / (Vrail − V)`, `Vrail = 0.1`, table + nearest lookup,
  `temp = index + 10`, 5-sample moving average, byte truncation. All from register-exact
  disassembly with verified −8 ROM-symbol identities and an IEEE-754 simulation that
  reproduces a sane curve (room temp, over-temp trip).
* Full 114-entry R/T table extracted verbatim from DROM.
* `Rref` ∈ {82, 33} kOhm chosen by GPIO19 at boot.
* Both chamber and PTC channels use identical math.

**Ambiguities / to verify on hardware:**
1. **Which Rref (82 vs 33)** applies to *this* board — read GPIO19, or pick the value that
   makes room temperature read ~20–25 °C. 82 kOhm is the more likely default.
2. **ADC attenuation / calibration match.** The firmware relies on ESP-IDF curve-fit
   calibration; ESPHome must read the same pin with calibration enabled so its volts equal
   the firmware's `V`. `0db` is recommended because the pin only reaches ~95 mV. If your
   ESPHome build reports voltage on a different scale, add a constant multiplier in the
   lambda so that ~55 mV → ~27 °C.
3. The `~33:1` input-scaling explanation for `Vrail = 0.1 V` is inferred (it makes the
   ratio produce true-kOhm resistances); it is not required for reproduction because the
   ESPHome ADC reads the same post-scaling pin voltage the firmware does.

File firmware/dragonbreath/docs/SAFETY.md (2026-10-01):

# Safety model

The Panda Breath heats a chamber with a **PTC ceramic element** switched by a
**solid-state relay**. Custom firmware controls that heater, so the safety story
matters. Good news: there are **two independent hardware backstops** that do not
depend on any firmware — this firmware is the third, soft layer.

## Layer 1 (hardware) — bonded thermal cutoff
A cylindrical thermal protector (bimetal KSD-type disc or one-shot thermal fuse)
is spliced **in series with the PTC's mains lead** and bonded to the heater
frame (confirmed on the real unit, photo IMG_7631). It sits **upstream of the
SSR**, so it opens on element over-temp **regardless of firmware and regardless
of the SSR failing shorted** — the classic worst-case failure.

## Layer 2 (physics) — PTC self-limiting
The element is a **PTC ceramic**: its resistance rises sharply at the Curie
temperature, collapsing its own power, so it is strongly **self-limiting** rather
than thermally runaway-prone. A firmware bug or a welded SSR should at most drive
the chamber toward the element's self-limited equilibrium, which the Layer-1
cutoff bounds. This is a strong physical safety margin, **not an absolute
guarantee** — no firmware can promise the absence of every fault.

## Layer 3 (this firmware) — soft cutoffs
`pb_heater` enforces, every control tick, before any heat request:
- **PTC element over-temp** → force off at 105 °C (stock parity). Always the first,
  unconditional, latching check.
- **Element foldback limiter** → below the 105 °C cutoff, the SSR is cut with
  hysteresis at a per-Rref point and held off until the element cools to a resume
  point, so a hot/slow element holds *under* the hard cutoff instead of ratcheting
  into it. Cut point is per-board (82 kΩ → 102 °C / 33 kΩ → 99 °C) or a user
  override `fb_cut` (90–104 °C). It can **only remove power**, can never exceed
  104 °C, and does not touch the fixed 105 °C hardware cutoff.
- **Chamber over-temp** → force off at 85 °C.
- **Sensor fault while heating** (open/short) → fail-closed.
- **Comms-loss watchdog** → if no controller link while heating for the watchdog
  timeout — **5 min by default, runtime-configurable to 10 s–5 min** (`comms_ms`,
  clamped to `[PB_HEATER_COMMS_TIMEOUT_MS_MIN, …_MAX]`; never disabled or beyond
  5 min) — latch off. (The device can't tell "idle hold" from "controller crashed",
  so a live link must be refreshed via `pb_heater_notify_link_alive()`.)
- **Set-point clamp** → target capped at the runtime `max` ceiling (default 70 °C),
  itself hard-bounded by `PB_HEATER_ABS_MAX_TARGET_C` (70 °C) — a target can never
  exceed the absolute cap regardless of settings.
- **Boot state** → SSR forced OFF in `pb_heater_init()` before anything else runs;
  a hung control loop trips the task watchdog (`CONFIG_ESP_TASK_WDT_PANIC`).

## Sensor calibration is bounded (cannot defeat a cutoff)
Each temperature channel (chamber, PTC) has a user-settable calibration
**offset** so a mis-reading sensor can be corrected. The offset is **hard-clamped
to ±5 °C** and the clamp is enforced **on every set AND on every NVS load** — a
corrupt or hand-edited stored value clamps to the bound, it is never applied raw.
The offset is applied inside `pb_ntc`, so the display, control regulation, AUTO,
and the over-temp cutoffs all act on the **same** calibrated value.

Because the offset is bounded to ±5 °C, the fixed cutoffs can shift by **at most
5 °C**: the chamber trips at **≥80 °C** worst case (85 − 5) and the PTC element at
**≥100 °C** worst case (105 − 5). The cutoff constants themselves
(`PB_HEATER_CHAMBER_MAX_C` = 85, `PB_HEATER_PTC_CUTOFF_C` = 105) are unchanged and
not user-configurable, and calibration touches only the reading, never the
sensor-fault fail-closed logic (which is raw-count based). Calibration therefore
**cannot disable a fault** or exceed the ±5 °C bound, and the Layer-1 bonded
thermal cutoff + Layer-2 PTC self-limit remain the true emergency layer regardless
of any offset.

## Front-panel panic-off (long-press)
Holding **any** front-panel button for 2 s latches the heater off and drops the
mode to OFF. It is called **panic-off**, deliberately, and is **not** a
safety-rated emergency stop — it is software running on the same MCU as the rest
of the control loop, so a firmware fault could defeat it. The Layer-1 bonded
cutoff and Layer-2 PTC physics remain the actual emergency layer.
The panic-off latch is RAM-only and clears on reboot (it is a manual stop, not a
hazard trip); reboot still starts with the SSR, mode, and target OFF, and never
restores an active heat command. Hazard-driven trips, by contrast, **persist** —
see below.

How it stays inside the safety model:
- The button task never writes the SSR GPIO. `pb_policy_request_panic_off()`
  sets the same mux-guarded latch as an over-temp trip
  (`pb_heater_request_panic_off()`, no GPIO write) and then wakes the control
  task, which drops the SSR from its own context — preserving the
  single-SSR-writer invariant.
- The wake means the drop happens on the very next control-task scheduling, not
  at the next 500 ms periodic tick. Host tests verify that the wake is issued
  before diagnostic logging, and the physical Panda bench verified the complete
  panic-off transition. Electrical long-event-to-SSR-low latency has not been
  instrumented, so no sub-20-ms measurement is claimed; that trace is optional
  characterization, not a safety or release gate.
- The transition is attributed to the button (not the generic safety path), so
  it invalidates any remote control lease immediately; a reconnecting
  dashboard/Klipper cannot silently restore heat.

A **long-press on Power while a fault is latched** attempts a fault clear instead
of a redundant panic. The clear only succeeds if the underlying condition has
recovered — the next control tick re-evaluates safety and re-latches if the trip
still holds, so an accidental press cannot revive an unsafe device.

## Persistent fault latch (survives a power cycle)
A **hazard-driven** safety trip — PTC/chamber over-temp, a sensor fault while
heating, or the comms-loss watchdog — is written to NVS on the latching
transition and **restored at boot**. A device that tripped and then lost power
comes back up **heater-OFF with heat/mode commands inhibited**, rather than
silently ready to heat, and stays that way until an **explicit** clear after the
condition has recovered (the next tick re-latches if it hasn't). The persisted
cause is a small, range-checked numeric code; a live reason string carries
session detail but is not persisted.

Boot restore is **fail-safe**: if the persisted state cannot be read reliably it
comes up latched (`persisted fault state unreadable`). A fresh device (no NVS
namespace yet) is not a fault. Clearing is **persist-first** — the NVS latch is
cleared *before* the RAM latch, so a failed persist keeps the heater latched and
the API returns HTTP 500 rather than falsely reporting the fault gone.

This is deliberately separate from heat resume: the persisted latch is the **only**
fault state that survives a reboot. The active mode, target, deadline, and lease
are never persisted — the device always boots OFF. The permanent inhibit
(`pb_heater_inhibit`) is likewise **not** persisted, so a power cycle lifts it (a
transient init failure must not brick the device across reboots).

## Residual-heat purge (session-gated, hysteresis)
After heat has run **this session**, the cooldown fan keeps running while the
chamber **or** PTC sensor is hot. The release temperature is the user-configurable
`cool_release` (30–65 °C, default 40 °C); the fan engages one 3 °C hysteresis band
above it and releases only once **both** sensors are below `cool_release` (an
unknown/faulted sensor keeps the fan on). It is strictly session-gated: the fan
**never** starts on temperature alone, and because that gate is RAM-only, a
**power-cycle-while-hot does not spin the fan**. A fault forces airflow ON
unconditionally, independent of this purge.

## Fan-only filtration is heater-independent and idle-only to enable
The manual filtration blower (`filter` command) and the AUTO fan-only filtration
band drive **only the blower** — they never engage the heater/SSR. Enabling manual
filtration is **idle-only**: turning it on while the heater is heating or the
cooldown purge is running is rejected (`heater_busy`, HTTP 409) so a status-page
toggle can't disturb an active heat cycle; turning it *off* is always allowed. The
AUTO band fails to no-airflow if disabled or if Moonraker disconnects.

## What is NOT protected
- **Over-current** is only the 6.3 A mains fuse. There is no PCB over-temp cutoff.
- Residual risk is chamber over-temp *up to the Layer-1 trip point* — identical
  to the stock firmware's failure ceiling.
- **Panic-off is not an emergency stop** (see above): a firmware fault could
  defeat it. Do not rely on it as your only means of making the device safe.

## Rule for contributors
Any code path that can energize `PB_GPIO_RELAY` must be reachable only after the
`pb_heater` safety checks. Never drive the SSR GPIO directly from another module.
Cross-task "off" requests (buttons, HTTP, watchdogs) must go through a
mux-guarded latch that converges on the next `pb_heater_tick()` — never call
`pb_heater_emergency_off()` (which writes the GPIO) from a task other than the
control task.

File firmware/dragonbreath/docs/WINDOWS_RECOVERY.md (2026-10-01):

# Recovering / restoring DragonBreath on Windows (USB)

`tools/flash.py` backs up, restores, or unbricks a Panda Breath over its on-board
CH340 USB-C bridge. You normally **don't** need this — installs and updates use the
no-USB web OTA (upload `dragonbreath-<ver>.bin` from the web UI). Use `flash.py`
only to:

- take a **stock backup** before your first install (the only guaranteed way back),
- **go back to stock** from a backup, or
- **unbrick** a board that won't boot.

You do **not** need to clone the repo — `flash.py` is a single self-contained file.

## 1. Install Python + esptool

Install Python 3.13 (this also installs the `py` launcher):

```
winget install Python.Python.3.13
```

**Close the terminal and open a new one** (so PATH updates), then install esptool
**with the `py` launcher**:

```
py -m pip install esptool
```

> ### Use `py`, not `python` — this is the #1 Windows gotcha
> Other apps (Inkscape, GIMP, …) ship their own `python.exe` that can sit *ahead* of
> the Python you just installed on your PATH. When that happens, `pip` installs
> esptool into one Python while `python flash.py` runs a *different* one that can't
> find it — you get `esptool not found` even though `pip` says it's already
> installed, in an endless loop. The **`py` launcher** always targets your real
> registered Python, sidestepping this entirely. Use `py` for **both** the install
> and the script.

## 2. Get flash.py

Download just this one file (no repo clone needed):

```
https://raw.githubusercontent.com/plastikman/DragonBreath/main/tools/flash.py
```

Save it somewhere simple (e.g. your Downloads folder) and `cd` there, or pass its
full path.

## 3. Plug in the board

Plug the Panda Breath's USB-C into the PC. Windows 10/11 usually installs the CH340
driver automatically and a **COM port** appears; `flash.py` auto-detects it. If no
COM port shows up in Device Manager, install the **WCH CH340 driver**, then re-plug.
You can force a port with `--port COM7`.

## 4. Run it (always `py`)

Take a stock backup **before** your first DragonBreath install — keep the file safe,
it's your only way back:

```
py flash.py --backup-only
```

Go back to 100% stock from a backup:

```
py flash.py --restore path\to\your-stock-backup.bin
```

You'll see esptool write the 4 MB image and print **`Hash of data verified`** — that
is the write confirmed. The board then reboots into the restored firmware. (There is
no separate post-write verify: the firmware rewrites its own NVS/calibration on first
boot, so a re-read would falsely "mismatch" — the inline hash above is the real
check.)

## Reset the config only (keep the firmware)

If the device is booting fine but you're locked out — wrong Wi-Fi, a forgotten
control token, or a bad saved setting — you don't need a full restore. Erase just
the config (NVS) region and the device comes back up unconfigured, serving its own
setup AP again:

```
py flash.py --erase-nvs
```

This clears Wi-Fi credentials, the control token, saved policy, and sensor
calibration; the firmware itself is untouched. It's the USB equivalent of the
on-device **Power + Auto reset combo** (hold both front buttons for 5 seconds — all
panel LEDs flash 3× to confirm, then the board reboots erased).

## Notes

- **Always `py`, never `python`.** If `py` somehow isn't available, use the full path
  to your real Python, e.g.:
  ```
  & "$env:LOCALAPPDATA\Programs\Python\Python313\python.exe" flash.py --restore ...
  ```
- `flash.py` needs only Python stdlib + esptool — nothing else from the repo.
- For a full USB *install* (not just backup/restore), download the release's
  `dragonbreath-<ver>-install-bundle.zip` instead — it bundles `flash.py` with all
  the firmware artifacts; unzip and run `py flash.py --build-dir .`.

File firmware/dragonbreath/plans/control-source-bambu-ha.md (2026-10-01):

# RFC: Pluggable control source — Klipper · Bambu · Home Assistant

Status: **✅ Implemented in v0.8.0.** All three sources now ship as a single-select
control source in `/setup` (mutually exclusive). **Klipper (Moonraker)** is the
default. **Home Assistant** shipped and was validated end-to-end (device + HA +
Mosquitto). **Bambu LAN** shipped as **experimental** — it builds and is safe by
construction, but is still unvalidated on a real Bambu printer; testers wanted. The
RFC below is retained as the design record.

## Goal

DragonBreath binds to **exactly one** control source at a time — never more than
one. Today that source is hard-wired to Klipper (Moonraker). This RFC generalizes
it to a **single, user-selected control source**:

| Source | Role | Status |
|---|---|---|
| **Klipper** (Moonraker) | Follow bed temp for AUTO; `M141`/`M191` + `output_pin` via the host helper | **Shipped** — the real target |
| **Bambu** | Follow the printer's bed temp over Bambu LAN MQTT (read-only) | **Proposed** (parity) |
| **Home Assistant** | HA is the controller: it sends target/mode over MQTT and reads back state | **Proposed** (parity) |

Only one is active per boot. This mirrors stock Panda Breath, which binds to a
single printer/controller. It is **not** "Bambu-in + HA-out simultaneously."

Non-goals: running two sources at once; sending *control* commands to a Bambu
printer (we only read status); a Bambu cloud path (LAN only).

## Why this is safe to ship untested behind a selector

The heater safety envelope is **independent of the control source**. Every cutoff
lives in `pb_heater`/`pb_policy` and runs regardless of who set the target:

- PTC 105 °C / chamber 85 °C fixed cutoffs, element foldback limiter, sensor
  fail-closed, comms-loss watchdog, boot-OFF, single-SSR-writer, `fb_cut`, the
  70 °C target ceiling — none of these consult the source.

A control source's *entire* job is to produce two numbers for AUTO
(`bed_c`, `connected`) and/or submit ordinary policy commands that any client
could already submit. So an untested Bambu/HA path can, at worst, mean **"AUTO
doesn't engage/track correctly"** or **"a command is missed"** — never unsafe
heating. That bound is what makes it defensible to ship these behind an
explicit, non-default selector and recruit testers.

Klipper stays the default. Selecting Bambu/HA is opt-in and labeled experimental.

## Current architecture (the seam we build on)

The whole "follow the printer" feature funnels through two values, fed once per
~500 ms control loop in `main/app_main.c`:

```c
// app_main.c ~194-198  (inside #ifndef CONFIG_PB_HIL_DEVBOARD)
if (s_net_up && s_mk_up) pb_moonraker_get_status(&st);
bool mk_connected = s_mk_up && st.state == PB_MK_SUBSCRIBED;
pb_policy_set_env(st.bed_temp, mk_connected);   // <-- the seam
```

`pb_policy` consumes only `bed_c` (float °C) and `connected` (bool). AUTO
engage/disengage hysteresis, LEDs, fail-off-on-disconnect, and the HTTP
`environment.moonraker_connected` field all derive from those. **A new source
plugs in by feeding this same seam** — nothing downstream changes.

Config plumbing today (to mirror): captive-portal `/setup` form →
`POST /save` (`components/pb_portal/pb_portal.c`, `save_post()`) → NVS namespace
`app_nvs`, keys `mk_host`/`mk_port` → `pb_moonraker_start()` reads NVS at boot.
There is no runtime settings path and no source selector yet.

## Proposed design

### 1. Control-source selector

New NVS key in `app_nvs`: `ctl_src` (u8) — `0=klipper` (default), `1=bambu`,
`2=ha`. On boot `app_main` starts **only** the selected client. `/setup` gains a
source `<select>`; the form reveals only that source's fields (small JS toggle).
Factory reset clears `ctl_src` back to Klipper.

`app_main` control loop generalizes the seam:

```c
float bed_c; bool connected;
pb_source_get_env(&bed_c, &connected);   // dispatches on ctl_src
pb_policy_set_env(bed_c, connected);
```

where `pb_source_*` is a thin dispatch over the one active client. Each client
keeps the `pb_moonraker`-style lifecycle API
(`start`/`set_config`/`get_config`/`get_status`/`clear_config`) for symmetry.

### 2. Bambu source — new `pb_bambu` component

MQTT-over-TLS client to the printer itself (the printer is the broker in LAN
mode). Mirrors `pb_moonraker`'s shape; uses ESP-IDF's bundled `esp-mqtt` +
`mbedTLS` (no new dependency).

Connection (all confirmed against OpenBambuAPI + ha-bambulab):

| Item | Value |
|---|---|
| URI | `mqtts://{printer_ip}:8883` (printer is its own broker in LAN mode) |
| Username | `bblp` (literal) |
| Password | printer **LAN Access Code** |
| TLS | self-signed cert, `CN = serial` — connect by IP, so **`skip_cert_common_name_check = true`**; bundle Bambu CA or run insecure on-LAN |
| Subscribe | `device/{serial}/report` |
| Request | `device/{serial}/request` |
| On connect | publish once: `{"pushing":{"sequence_id":"0","command":"pushall","version":1,"push_target":1}}` (**required** on P1/A1 which send deltas; harmless on X1). Never re-`pushall` more than every 5 min on P1. |

Report fields we read (top-level of the `print` object):

- `bed_temper` (°C float) — **the follow signal; universal across all models**
- `gcode_state` — `IDLE`/`PREPARE`/`RUNNING`/`PAUSE`/`FINISH`/`FAILED` (note
  `FINISH`, not `FINISHED`) → maps to the six-state printer model
- `chamber_temper` — informational; **only X1/X1C/X1E/H2/P2-class** report it.
  On H2/newer it moved to a packed nested field
  `device.ctc.info.temp` (`cur = v & 0xFFFF`, `tgt = (v>>16) & 0xFFFF`) — parse
  both forms. P1/A1 have no chamber sensor (we follow the bed anyway).

RAM discipline on the C3 (~400 KB SRAM): a full `pushall` report is **10–15 KB+**.
Do **not** cJSON-parse the whole blob (raw buffer + parse tree ≈ double RAM).
Use a **targeted/streaming scan** (jsmn or hand-rolled) that extracts just
`bed_temper` / `gcode_state` / `chamber_temper`. Tune `sdkconfig`: keep
`MBEDTLS_SSL_IN_CONTENT_LEN` at 16384 if the printer needs it, shrink
`MBEDTLS_SSL_OUT_CONTENT_LEN` to ~2048 (we send tiny commands). Measure
`esp_get_free_heap_size()` around the TLS handshake on real hardware to finalize
buffers.

New NVS keys (`app_nvs`): `bb_host`, `bb_serial`, `bb_code`. `/setup` gains those
three fields when Bambu is selected.

### 3. Home Assistant source — new `pb_ha` component

Plain MQTT client to the **user's** broker (Mosquitto/HA add-on) — HA is the
controller. Two directions on one connection:

- **Subscribe** a command topic → translate HA messages into ordinary
  `pb_policy` commands (power_on/target, off, mode). These are the same commands
  a web/klipper client already issues, so no new authority is granted.
- **Publish** a retained state topic — the flat schema stock already uses, which
  we captured from a live unit:
  ```json
  {"chamber_temp":24,"work_on":"ON","mode":"power on","target_temp":45,
   "filter_temp":30,"heater_temp":80,"drying_remaining_min":720,
   "drying_running":"OFF","printer_ip":"...","printer_name":"...","printer_bind":"bind"}
  ```
  Optionally emit HA MQTT-discovery config so entities auto-appear.

New NVS keys: `ha_host`, `ha_port`, `ha_user`, `ha_pass`, `ha_topic` (prefix).
`/setup` reveals these when HA is selected.

Note: HA does **not** feed the AUTO bed-follow seam (there's no printer bed to
follow); in HA mode `pb_source_get_env` reports `connected=false`/no bed, and HA
drives target/mode directly. That asymmetry is intentional and matches stock.

### Shared MQTT plumbing

Bambu and HA both need an MQTT client; only one runs at a time. Options: a thin
internal `pb_mqtt` helper both call, or two independent components. Recommend
starting with two components sharing a small static TLS/connect helper, to keep
Bambu's TLS quirks out of the plain-broker HA path. Decide during implementation.

## Implementation phases

1. **Source selector scaffolding** — `ctl_src` NVS key, `pb_source_*` dispatch in
   `app_main`, `/setup` `<select>` + field-reveal JS, factory-reset handling.
   Klipper remains default; behavior byte-identical when `ctl_src=0`.
2. **`pb_bambu`** — esp-mqtt/TLS client, `pushall` on connect, streaming scan for
   `bed_temper`/`gcode_state`/`chamber_temper`, feed the seam, reconnect+backoff.
   `sdkconfig` TLS buffer tuning.
3. **`pb_ha`** — broker client, command-topic → policy commands, retained state
   publish, optional MQTT discovery.
4. **Docs** — `/setup` help, `FEATURES.md`/`OEM_PARITY.md` (Bambu/HA rows flip to
   "Implemented (community-tested)" only after real-hardware confirmation),
   per-source setup instructions.

Phases 1–3 are buildable and CI-verifiable (compile + host tests) **blind**.
None can be marked validated without a tester.

## What a tester needs to do

**Bambu:** a printer in **LAN Only Mode**; note the **Access Code** and
**serial**; give the printer a static DHCP lease. Select "Bambu" in `/setup`,
enter IP + serial + code. Verify: connects, `bed_temper` shows in the dashboard,
AUTO engages when the bed crosses the threshold, and it fails safe (heater off)
when the printer/Wi-Fi drops. Report model + firmware version. Known gotchas to
watch: **single-client limit** on P1/A1 (only one LAN MQTT client — HA/Bambu
Studio/Handy will contend), and the 2025 authorization-control firmware (status
*read* still works with access code; we never send control commands).

**HA:** an MQTT broker; select "Home Assistant", enter broker + creds. Verify
state topic publishes, HA can command target/mode, entities appear.

## Open questions

- Bambu TLS: bundle the Bambu CA (more correct) vs `skip-verify` on-LAN
  (simplest)? Lean CA-bundle + `skip_cert_common_name_check`; needs the CA PEM.
- Streaming JSON: adopt `jsmn` (adds a small dep) vs a hand-rolled field scan?
- HA command schema: match stock's exact topic/payload for drop-in parity, or
  define a clean DragonBreath schema + discovery? (Affects existing stock-HA
  users migrating.)
- Selector UX: `/setup` `<select>` (proposed) vs a compile-time Kconfig per
  build. Runtime selector is friendlier for a single binary.

## Sources

Bambu LAN protocol (topics, `pushall`, fields, ports, `bblp`/access-code, TLS
CN=serial, model/chamber matrix, single-client limit, 2025 auth control):
OpenBambuAPI (`mqtt.md`, `tls.md`) and Home Assistant `ha-bambulab`
(`pybambu/bambu_client.py`, `pybambu/models.py`). HA state schema: captured from a
live stock v1.0.4 unit.

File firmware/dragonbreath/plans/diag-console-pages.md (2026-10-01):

# RFC: `/diag` and `/console` web pages

Status: **✅ Implemented in v0.8.0.** Two read-only, non-interactive web pages served
by the device — a diagnostics telemetry view (`/diag`) and a firmware console log
(`/console`, backed by the auth-gated `GET /api/v2/console`) — themed to match `/fw`
and `/setup`, each with a `[Download]` button. No on-device persistence. The RFC below
is retained as the design record.

## Motivation

The new BIGTREETECH Panda revision **has no external USB port** — the first
DragonBreath install means opening the unit, and after that there is **no way to
reach the serial console without opening it again**. On top of that, **release
builds repurpose the UART TX pin (GPIO21) as the Power LED** (`CONFIG_PB_POWER_LED`),
so a shipped device effectively has *no* serial console at all: `ESP_LOGx` output is
generated but goes nowhere reachable.

So the only practical way to see what the firmware is doing — boot sequence,
Wi-Fi/mDNS/broker chatter, warnings, a fault's context — is **over the web**. That
is what `/console` is for. `/diag` is the companion: a live telemetry view (the
`tools/diag.py` logger, in the browser) so you don't have to run a host script.

## What already exists (so we don't rebuild it)

- **`/api/v2/state` + SSE `/api/v2/events`** — full telemetry (chamber, PTC/element,
  SSR output, mode, fault+reason, sensor status), pushed ~every 2 s and on every
  transition. `tools/diag.py` is just a 2 Hz poll of this plus a client-side running
  peak + CSV.
- **`/api/v2/logs`** — the **event ring** (`pb_evlog`, 64 × 96 B `{ms,text}`), the
  *curated* notable events (mode/fault transitions). **Already rendered** in the
  dashboard's Settings → "Event log". This is NOT the raw `ESP_LOGx` stream — nothing
  captures that today.

Implication: `/diag` is almost entirely a **new front-end over existing data**;
`/console` needs a **new capture path** (the raw log stream is not retained anywhere).

## Feature 1 — `/diag` (telemetry view)

Client-side page, **zero new device RAM**. Reuses SSE + `/api/v2/info` (for
`rref_kohm`). Presents what `diag.py` prints:

- chamber temp, element (PTC) temp, SSR output, mode, fault + reason, sensor status,
- **running peak element temp** (computed in-browser since page open),
- a live trend (reuse the dashboard's chart),
- **`[Download]` → CSV** of everything accumulated in the browser since the page was
  opened (same columns as `diag.py`: `t_s,chamber_c,ptc_c,ptc_status,out,mode,fault,reason,peak_c`).
  Generated in-page; nothing is stored on the device.

Caveat: it's a *live* view at SSE cadence (~2 s + transitions). It cannot back-fill
history from before the page opened — the device keeps no telemetry log (only the
64-event ring). Reviewing a *past* print's full time-series would require on-device
flash logging, which is explicitly **out of scope** (see below).

## Feature 2 — `/console` (firmware log stream)

The genuinely new capability: capture the `ESP_LOGx` stream into a RAM ring and serve
it.

- **Capture:** install an `esp_log_set_vprintf` hook that (a) formats the line into a
  fixed **static byte ring** and (b) forwards to the original vprintf so UART output
  (where wired) is unchanged. Byte ring (not fixed line slots) to avoid per-line
  padding waste and handle variable-length lines.
- **Size:** **16 KB** (~180 lines). Static allocation, never grows. See RAM analysis.
- **Boot capture:** initialise the ring + hook **very early in `app_main`**, before
  other subsystem init, so the **boot sequence is captured** (the whole point on a
  no-USB device).
- **Concurrency:** the hook runs from many task contexts and must be **lock-safe,
  non-blocking, and non-recursive** (never log from inside the hook; guard the ring
  with a portMUX spinlock or a lock-free single-writer discipline). It must not call
  anything that can block or re-enter the logger.
- **Endpoint:** `GET /api/v2/console` returns the ring as `text/plain` (oldest →
  newest, wrap handled). The page polls it (~1–2 s; SSE is possible later but polling
  is simpler and the volume is low).
- **`[Download]`** → save the current ring as `dragonbreath-console.txt`.

## RAM analysis (measured on the bench)

The `/diag` view costs zero device RAM. The console ring is the only new cost.

| Mode | Transport | Free heap | Min watermark |
|---|---|---|---|
| Klipper | WebSocket (no TLS) | ~156 KB | **~121 KB** (14 h uptime) |
| HA | plain MQTT :1883 (no TLS) | ~153 KB | ~142 KB (fresh boot) |
| Bambu | MQTT-over-TLS (mbedTLS) | — | **not yet measurable** (no printer) |

Bambu is the RAM worst case (only mode pulling in mbedTLS); a TLS 1.2 handshake peaks
~25–45 KB. Pessimistically: ~121 KB − ~45 KB TLS − 16 KB ring ≈ **~60 KB free** at the
worst instant — comfortable. A 16 KB static ring is a fixed, one-time reduction and
does not interact with the TLS spike dynamically. **RAM is not a constraint**; re-check
the Bambu/TLS headroom on hardware once a tester has a printer.

## Shared scaffolding

Both pages reuse the existing themed chrome (`PAGE_HEAD` / `PAGE_HDR` / `WRAP_OPEN`,
light-dark tokens, product header, `DB_AUTH_JS`) exactly like `/fw` and `/setup`.
Registered as `GET /diag` and `GET /console` in `pb_portal`. Factor the shared bits
while adding `/diag` first.

## Decisions

- **Ring size:** 16 KB (~180 lines) — headroom is ample and more scrollback is more
  useful for a boot/debug log reachable only over the web.
- **Auth:** `/diag` **open** (telemetry only, same as the dashboard reads).
  `/console` **gated behind the control token** — the raw log is chattier (IPs,
  Wi-Fi/mDNS detail) and it's a debug tool; falls back to open when no token is set,
  consistent with the rest of the UI.
- **Non-interactive:** both are strictly read-only. No command input on `/console`,
  so there is no injection surface.
- **Capture scope:** tee whatever the build already logs (release = INFO and up);
  no separate log-level control in v1.

## Implementation plan

1. **`/diag`** (front-end only, zero firmware risk): shared page scaffolding + the
   SSE-driven telemetry view + client-side CSV download.
2. **`/console`**:
   - `pb_evlog` (or a new `pb_conlog`) gains a 16 KB byte ring + `esp_log_set_vprintf`
     hook, initialised early in `app_main`.
   - `GET /api/v2/console` (auth-gated) returns the ring as text.
   - `/console` page (themed, polling, auto-scroll, `[Download]`).
3. Docs: `FEATURES.md` / `api-v2.md` note the two pages + the `/api/v2/console`
   endpoint; mention the no-USB / TX=LED rationale.

## Out of scope

- **On-device persistence / flash logging.** Neither page stores data; both are live
  windows (telemetry since page-open; the rolling 16 KB log ring). Reviewing a past
  print's full history is a separate, larger design (wear, flash budget) and is not
  part of this.
- Interactive console / command input.
- An SSE log stream (polling is enough for v1; can add later).

## Open questions

- Confirm the `esp_log_set_vprintf` hook composes cleanly with the existing UART
  console and the `CONFIG_PB_POWER_LED` TX-repurposing (verify on a release build).
- Ring size final (16 KB proposed) vs. a `Kconfig`-tunable.
- Whether `/console` should also fold in the `pb_evlog` curated events inline, or keep
  them separate (Settings already shows the event ring).

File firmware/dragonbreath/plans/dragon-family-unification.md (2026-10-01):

# RFC: Dragon firmware family unification

Status: **Accepted; implementation in progress.** Updated after the initial
dragon-core extraction landed in DragonBreath via
[#68](https://github.com/plastikman/DragonBreath/pull/68).

The Dragon family uses one board-neutral ESP-IDF core and thin product firmware
repositories. Products own their hardware and safety behavior; dragon-core owns
services and transports that can be reused without product-specific GPIO, sensor,
or actuator assumptions.

## What has landed

As of 2026-08-09:

- [`justinh-rahb/dragon-core`](https://github.com/justinh-rahb/dragon-core) exists and
  uses the family-neutral `dc_` / `DC_` namespace.
- DragonBreath #68 extracted `dc_evlog`, `dc_source`, `dc_bambu`, `dc_wifi`, and
  `dc_moonraker`. Follow-ons added `dc_mqtt`, the `dc_ui` family SPA, and the
  `dc_portal` provisioning/recovery plane. DragonBreath consumes all eight through
  ESP-IDF Component Manager manifests pinned to one dragon-core release.
- The extraction preserved NVS namespaces, keys, and persisted enum values. Existing
  Wi-Fi, Moonraker, Bambu, and control-source configuration survives the upgrade.
- DragonBreath's product-local policy command-origin enum now uses `db_source_t` and
  `DB_SOURCE_*`, keeping it distinct from dragon-core's `dc_ctl_source_t` and
  `DC_SRC_*` control-source selector.
- DragonBreath #68 passed host tests, its ESP-IDF CI build, and the complete safe
  ESP32-C3 devboard HIL suite: 3 scenarios, 66 steps, 0 failures, with Panda mains
  GPIO/ADC backends compiled out.
- dragon-core has annotated releases through `v0.5.4`. Its CI runs host and family-SPA
  checks and compiles/links every shared component together with ESP-IDF 5.3 for
  ESP32-C3.
- dragon-core owns the editable SPA, HTTP server lifecycle, captive DNS, provisioning,
  OTA upload, logs and reset transport. DragonBreath supplies product routes, schema,
  persistence, authorization and safety callbacks. `/api/v2/info` supplies an additive
  UI schema/product descriptor, and the SPA gates optional Manual/Auto/Dry surfaces
  from runtime capabilities.

## Namespace and compatibility rules

| Ownership | C/component namespace | Status |
|---|---|---|
| dragon-core shared code | `dc_*` / `DC_*` | Active |
| DragonBreath product code | `db_*` / `DB_*` | Target convention |
| DragonVent product code | `dv_*` / `DV_*` | Target convention |
| Existing DragonBreath `pb_*` / `PB_*` | Transitional legacy | Migrate in focused follow-ups |

New DragonBreath components use `db_*`; existing `pb_*` components are not precedent
for new names. In particular, new app-side Klipper MQTT work should use
`db_klipper_mqtt`, while an independently reusable transport would be a `dc_*`
component.

The source namespace may change, but compatibility-sensitive identifiers do not
change merely for naming consistency. Preserve these unless an explicit migration is
designed and tested:

- NVS namespaces, keys, and numeric enum values;
- HTTP routes, JSON fields, auth headers, and other wire contracts;
- partition labels and OTA/project identities;
- persisted configuration strings and externally consumed names.

The remaining `pb_*` to `db_*` source rename should be mechanical and isolated from
behavior changes. Compatibility exceptions are intentional, documented exceptions to
the source-prefix rule.

## Architecture

### Shared core

The landed core owns:

| Component | Responsibility |
|---|---|
| `dc_evlog` | Event and diagnostic-console rings |
| `dc_source` | Persisted external-control source selection |
| `dc_bambu` | Bambu LAN MQTT status client |
| `dc_wifi` | Wi-Fi, provisioning, scanning, and mDNS with product identity input |
| `dc_moonraker` | Moonraker WebSocket client and Klipper status |
| `dc_mqtt` | Shared ESP-MQTT session lifecycle and event callbacks |
| `dc_ui` | Embedded family SPA asset and capability-aware browser shell |
| `dc_portal` | HTTP server, captive provisioning, OTA, logs and recovery transport |

Candidate follow-on modules include discovery and group management and reusable RGB
LED behavior. A candidate moves to core only after
its product hardware and policy dependencies are behind a narrow capability boundary.

### Products

Products retain board maps, sensors, actuators, safety policy, and product composition:

```text
dragon-core (dc_*)                 product repositories
  transport and service code        DragonBreath: db_* target; legacy pb_* remains
  no product GPIO assumptions        DragonVent:   dv_*
  no heater/motor policy              DragonStatus: product/controller-board layer
```

The proposed `dc_device` capability boundary is a follow-on seam, not something #68
already implemented. DragonBreath would provide a `db_device` implementation;
DragonVent and DragonStatus would provide their own product implementations.

## Shared web client and same-LAN management

The UI is already a browser-hosted SPA. Today it uses HTTP requests plus server-sent
events; the firmware's Moonraker client, not the browser UI, is the current WebSocket
consumer. When the UI becomes the family SPA, the bundle can carry sibling-product
screens once and select them from device capabilities; no native mobile app is
required.

The management-plane follow-on is intentionally same-LAN and opt-in:

1. A user enables sibling discovery in configuration.
2. The device discovers other Dragon-family devices on the LAN and presents them for
   explicit selection.
3. Selected devices form a group; membership is reflected to the group members.
4. Opening any group member's UI presents the selected siblings in one tabbed or
   otherwise unified pane.
5. The browser maintains a live session with each selected device so every view stays
   current. This can extend today's HTTP/SSE model or introduce a family WebSocket
   transport after measuring device and browser constraints.

Discovery must not imply authorization or control. Product differences are expressed
through capabilities, and grouping remains explicit rather than silently claiming
every device found on the subnet.

## Delivery sequence

1. **Initial core extraction — complete.** dragon-core stood up; five components
   extracted; DragonBreath #68 merged after CI and hardware HIL.
2. **MQTT-Klipper coordination — complete.** `DC_SRC_KLIPPER_MQTT = 4` landed in
   dragon-core while preserving `DC_SRC_NONE = 3`, with an exclusive `DC_SRC_MAX`;
   DragonBreath #67 was rebased onto the `dc_*` API and merged.
3. **Finish product source namespacing.** Migrate remaining DragonBreath-owned
   `pb_*`/`PB_*` identifiers to `db_*`/`DB_*` in a focused change. New app code uses
   `db_*` immediately; persisted and wire identifiers remain compatible.
4. **Decouple and extract the web layer — complete.** #69 moved the static family SPA
   into `dc_ui`; #73 adds `dc_portal` and reduces DragonBreath to product API routes,
   schema, persistence, authorization and safety callbacks.
5. **DragonVent.** Create a fresh firmware repository on dragon-core, with `dv_*`
   board/motor/device code. Archive OpenVent with a pointer after replacement hardware
   behavior is proven.
6. **DragonStatus.** Build one product family for Panda Status, Pop Status, and Panda
   LUX P2, which share a controller board. Model product variations as capabilities or
   configuration. Evaluate the Vent RGB implementation as a reusable `dc_*` LED module
   that products can specialize.
7. **Same-LAN single pane.** Add opt-in discovery, explicit grouping, multi-device
   live sessions, and the unified family SPA after the device/capability contract is
   stable.

## Repository ownership and releases

The current, working home of the shared core is `justinh-rahb/dragon-core`. Moving the
core and products into a jointly owned organization remains an organizational option,
not a prerequisite and not a completed decision.

Products should pin every selected core component to one tag or one full commit from
the same core revision. DragonBreath currently uses `v0.5.4`. dragon-core's own
ESP-IDF compile fixture commits its dependency lock; DragonBreath currently regenerates
and ignores its application lock, so its component manifests are the reviewed pin.

## Non-goals of the extraction

- No API v2, OTA, or revert-to-stock behavior change.
- No product hardware policy in dragon-core.
- No native management app; the browser SPA is the client.
- No forced NVS or wire-format rename to match source namespaces.
- No claim that every candidate module is shared before two products validate its
  boundary.

## Open decisions

1. The exact `dc_device` capability contract and where each product implementation
   lives.
2. Whether Klipper helpers remain per-product or converge after DragonVent has a real
   Klipper use case.
3. The discovery protocol, group-membership persistence, browser trust model, and
   whether multi-device live state uses SSE/HTTP or a new WebSocket transport.
4. Which RGB behaviors are generic enough for core versus product-specific policy.
5. Whether and when the repositories move into a jointly owned organization.

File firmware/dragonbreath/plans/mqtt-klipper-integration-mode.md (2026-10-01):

# RFC: MQTT-only Klipper integration mode

Status: **Accepted specification.** The grounded implementation design and firmware
work are tracked in [#67](https://github.com/plastikman/DragonBreath/pull/67). This
revision incorporates the Moonraker/Klipper documentation findings recorded there and
the dragon-core extraction landed in #68.

## Goal and positioning

Provide bidirectional DragonBreath control and telemetry using a central MQTT broker,
`moonraker.conf`, and `printer.cfg` macros, without installing anything in
`klippy/extras/`.
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

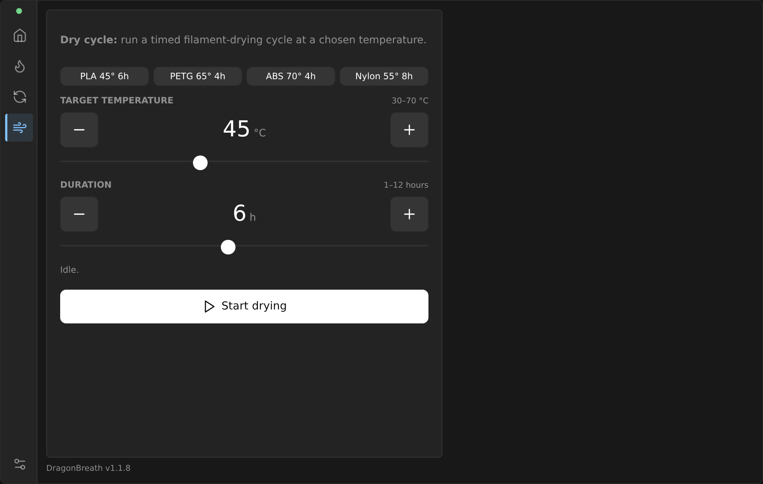
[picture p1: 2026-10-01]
firmware/dragonbreath/docs/screenshots/dry.png

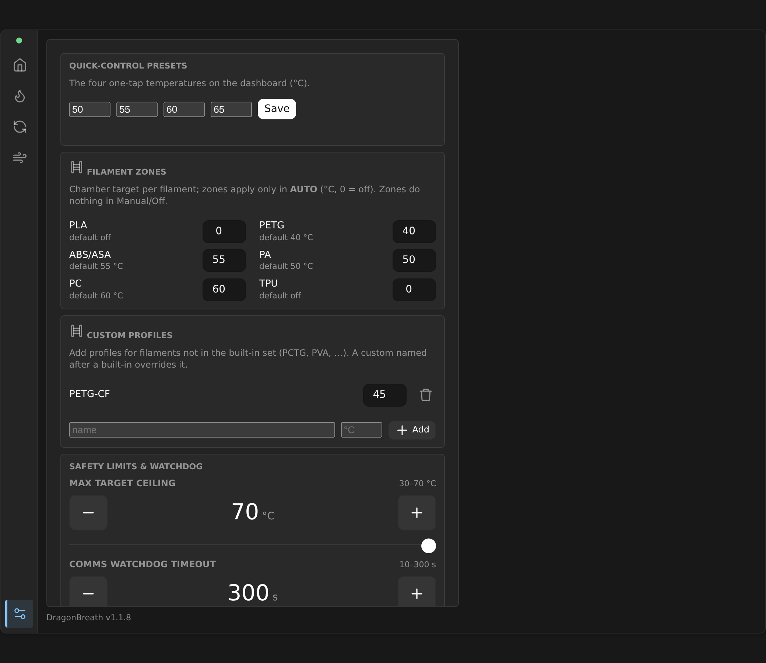
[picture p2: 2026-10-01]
firmware/dragonbreath/docs/screenshots/settings.png

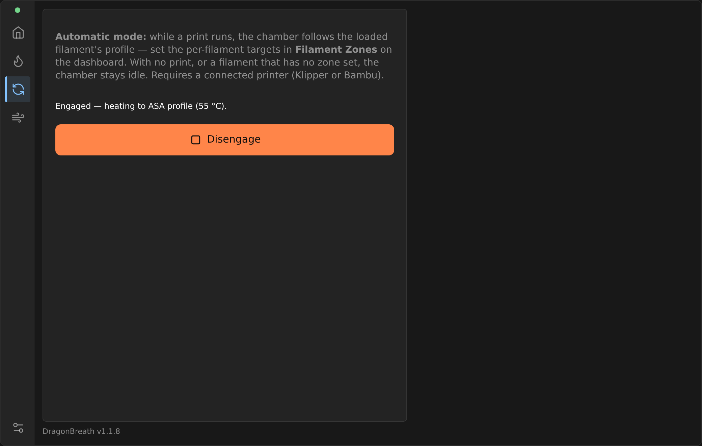
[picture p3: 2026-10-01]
firmware/dragonbreath/docs/screenshots/auto.png

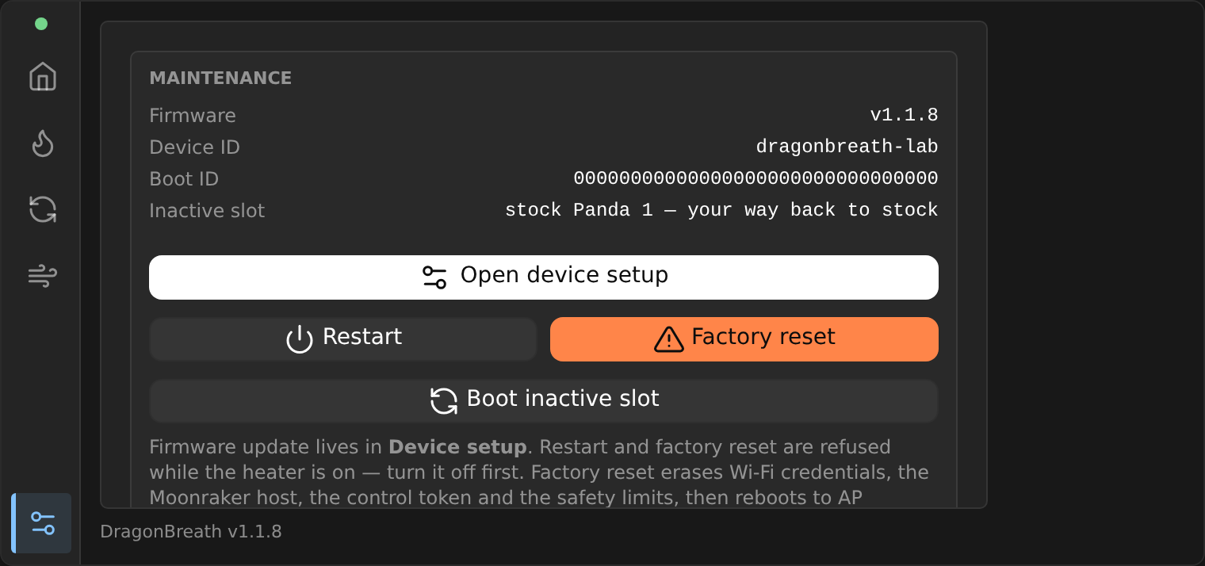
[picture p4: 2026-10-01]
firmware/dragonbreath/docs/screenshots/revert.png

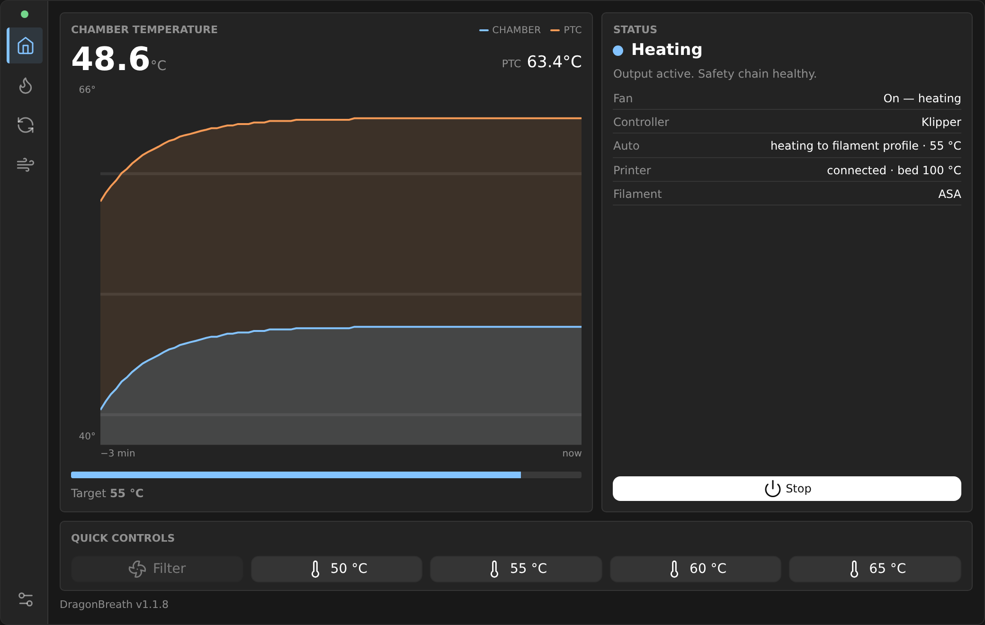
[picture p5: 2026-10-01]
firmware/dragonbreath/docs/screenshots/dashboard.png

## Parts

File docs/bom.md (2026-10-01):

# Bill of materials

Prices are rough 2026 US retail. "Example" parts are ones that match the spec; any part with
the same ratings works. Confirm the three outer dimensions of the PTC element you buy and put
them in `cad/u1breath/params.py` (see `docs/measurements.md`).

## Heater and air

| Qty | Part | Spec | Example / notes | ~USD |
|---|---|---|---|---|
| 1 | PTC air heater element | 110 V, 300 W, insulated, finned, with bundled normally-closed thermal protector (about 150 C). Typical body 150 x 32 x 26 mm | AliExpress/Amazon "110V 300W insulated PTC ceramic air heater". The 120 V US supply pushes it slightly above nameplate; the element self-limits | 12 |
| 1 | Thermal fuse | 130 C, 10 A, 250 V, axial (TF type). One-shot backstop strapped to the liner | Microtemp G4A01130 or equivalent | 2 |
| 1 | Blower | 7530 centrifugal, 24 V DC, 2-wire, ball bearing preferred, 15 to 20 CFM, 0.15 to 0.25 A | GDSTIME 7530 24 V, Sunon/ Delta equivalents | 9 |
| 4 | HEPA cells | 80 x 40 x 15 mm (you have these) | | 0 |
| 2 | Carbon fill | pellet activated carbon, about 60 g per cartridge | your Amazon pellet carbon | 0 |
| 1 | Aluminum sheet | 1.0 mm, 5052 or 3003, 200 x 160 mm minimum, for the folded liner and outlet flange | hardware store or McMaster 89015K18 | 8 |
| 1 | Aluminum mesh (optional) | fine mesh for the carbon cartridge faces if you prefer not to print mesh | | 4 |

## Electronics

| Qty | Part | Spec | Example / notes | ~USD |
|---|---|---|---|---|
| 1 | MCU board | Seeed XIAO ESP32-C3 with u.FL antenna | the external antenna matters inside a metal printer | 6 |
| 1 | 2.4 GHz antenna | u.FL, flexible FPC or short dipole, 50 to 100 mm lead | mounted on the plastic shell, away from the liner | 3 |
| 1 | AC-DC module | HLK-10M24, 24 V 0.42 A, 100 to 240 V in, rated to 70 C | Hi-Link | 6 |
| 1 | Buck module | 24 V to 5 V, 1 A, rated to 70 C | MP1584 mini module set to 5.0 V | 2 |
| 1 | SSR | PCB-mount, zero-cross, 10 A at 240 VAC, 3 to 32 VDC input | Omron G3MB-202P is only 2 A: do not use. Use a 10 A class part (e.g., "MGR-1 D4810" style on a small carrier, or a 10 A G3NA-210B with its heatsink if the bay is widened) | 8 |
| 1 | MOSFET module | logic-level N-channel, 3.3 V gate drive, for 24 V fan PWM at 25 kHz | D4184 module, or AO3400 on a breakout | 2 |
| 3 | NTC thermistor | 100K, Beta 3950, 1%: one glass bead for chamber air, one ring-lug M3 type for the duct wall, one ring-lug M3 type for the bed probe | Klipper's standard sensor; ring-lug types from 3D printer bed-thermistor listings | 6 |
| 3 | Resistor | 100 kOhm, 1%, 0603 or through-hole, NTC divider | | 0.5 |
| 1 | WS2812B LED | single 5 mm or 5050 on a tiny breakout | status LED behind a translucent window | 1 |
| 1 | Fuse holder + fuse | panel or inline 5 x 20 mm holder, 5 A slow-blow (T5A 250 V) | | 3 |
| 1 | Terminal block | 3-position, 10 A, screw or lever (Wago 221-413 x2) | mains junction inside the electronics bay | 3 |
| 1 | Power cord | 18 AWG SJT, 3-conductor, grounded, 1.8 m, bare end | the earth conductor bonds to the liner | 8 |
| 1 | Cord grip | PG7 or M12 strain relief, nylon | | 1 |
| 1 | Rubber grommet | for the Sterilite cover hole, sized to the cord | | 1 |
| 1 | JST-XH 2-pin pair | bed probe connector on the unit | | 1 |
| 1 | JST-XH 2-pin pair | blower connector (most blowers come with XH 2.54) | | 1 |
| | Wire | 18 AWG silicone high-temp for mains inside the bay, 24 AWG silicone for sensors, 600 mm 2-conductor silicone lead for the bed probe | | 5 |
| | Crimps | insulated spade/ring crimps for the PTC and fuse holder leads, ferrules for the terminal block | | 3 |
| 1 | Heat-shrink | assorted, plus a few glass-fiber sleeves for the PTC leads | | 2 |

## Mechanical and consumables

| Qty | Part | Spec | ~USD |
|---|---|---|---|
| 24 | Heat-set inserts | M3 x 5.7 mm (OD 4.0), brass | 4 |
| 24 | Screws | M3 x 8 button head | 2 |
| 8 | Screws | M2 x 6 (carbon cartridge lids) + M2 inserts | 2 |
| 4 | Mounting | M4 x 12 + nuts or 3M VHB 5952 pads, depending on the rear wall | 3 |
| 1 | Kapton tape | 20 mm | 3 |
| 1 | Thermal epoxy or a dab of RTV | bed probe retention | 4 |
| 1 | High-temp foam tape | 3 mm silicone foam, seals the filter grille and liner flange | 4 |
| | Filament | about 350 g ASA or ABS | 10 |

Total, excluding filters and carbon you already own: roughly 120 to 150 USD.

## Why these ratings

- 300 W at 120 V is 2.5 A. Fuse at 5 A slow-blow so PTC inrush (about 2x for a second) does
  not nuisance-trip. SSR at 10 A gives 4x margin for derating at 60 C chamber temperature.
- Blower at 24 V keeps the HLK-10M24 as the only AC-DC converter. The XIAO draws under 150 mA
  at 5 V through the buck.
- Every active part is rated for at least 70 C ambient because the whole unit lives at
  chamber temperature.

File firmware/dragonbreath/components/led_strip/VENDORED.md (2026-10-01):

Vendored from https://github.com/espressif/idf-extra-components (led_strip 3.0.3,
Apache-2.0) so the U1 Breath build does not depend on the Espressif component
registry. Only the sources, headers, license and manifest are kept.

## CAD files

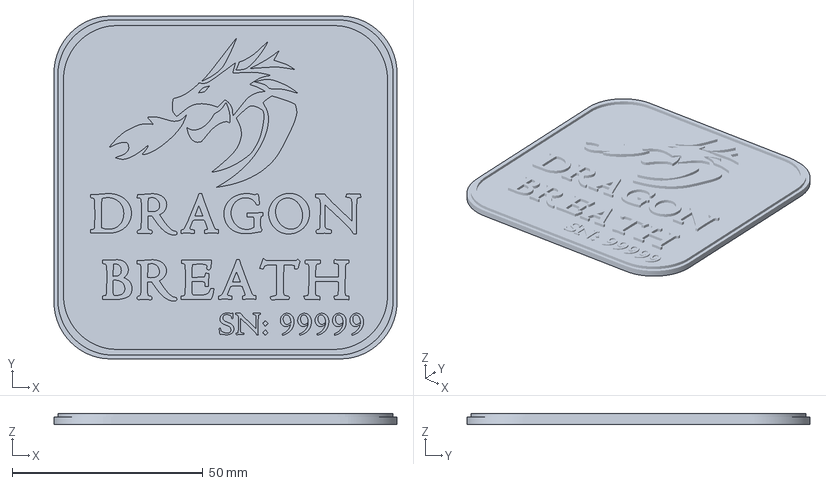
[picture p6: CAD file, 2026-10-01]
firmware/dragonbreath/misc/dragonbreath-logo-plaque.3mf
90.0 x 90.0 x 3.00 mm

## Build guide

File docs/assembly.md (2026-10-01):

# Assembly

Part names match `cad/build.py` output in `cad/out/stl/`. Print everything in ASA
(ABS is fine). Before printing, fill in `cad/u1breath/params.py` from
`measurements.md` and re-run `python cad/build.py`.

## Print settings

| Part | Qty | Orientation | Notes |
|---|---|---|---|
| back_plate_lower, back_plate_upper | 1 each | flat, back face down | 4 walls, 30 % infill; the two halves lap-joint at Z 140 to 150 because a 273 mm plate does not fit the 256 mm bed. `back_plate` (one piece) is exported for reference only |
| filter_bay_body | 1 | front face down | boss columns print as plain walls, no overhangs |
| intake_grille | 2 | flat | 0.2 mm layers, slots print without support |
| hepa_retainer | 2 | flat | goes into each bay first, rests on the stop lip at the back of the bore |
| carbon_cartridge | 2 | mesh face down | 2 mm openings, 1 mm bars; or print the frame and glue aluminum mesh |
| carbon_cartridge_lid | 2 | flat | |
| mid_body | 1 | front face down | blower and electronics bay; the PG7 hole is in the high-X side wall |
| electronics_cover | 1 | flat, outside face down | LED window: pause and insert a clear PETG square, or print the window in natural ASA |
| heater_shell | 1 | front face down | ASA only here, it sees the warmest air; side walls are 2 mm by design |
| heater_liner (STEP) and heater_liner_flat (DXF) | 1 | not printed | aluminum, see below; the slotted outlet plate is the second outline in the DXF |

Reference exports that are not printed: `blower_keepout`, `electronics_keepouts`, `ptc_keepout` (STEP/STL volumes used by the clearance tests).

Orientation note: with Y = 0 at the rear wall and Z up, +X runs to your left when you face the unit from inside the chamber. The blower sits at low X, the electronics bay at high X.

Heat-set inserts: M3 x 5.7 (OD 4.0) in every 4.0 mm boss hole; M2 in the cartridge
lids. Set them with a soldering iron at 230 C, press slowly, let the plastic flow.

## Aluminum liner

1. Print `cad/out/dxf/heater_liner_flat.dxf` at 1:1 on paper and spray-glue it to
   1.0 mm aluminum sheet, or send the DXF to a laser shop. The DXF holds two
   outlines: the folded box (layers OUTLINE, HOLES, BEND) and the flat slotted
   outlet plate that screws onto the box's 16 mm lips.
2. Cut the outline and the outlet slots (a nibbler or a Dremel cut-off wheel for the
   slots, file the burrs; any burr facing the airflow whistles).
3. Drill the thermal-fuse tab hole, the NTC ring-lug hole, and the PE bond hole (all
   M3 clearance, 3.2 mm).
4. Fold on the bend lines in a vise with two pieces of angle iron. The flange with
   the slots faces +Y (the chamber). Rivet or M3 the tabs.
5. Test fit the PTC element: it should slide in with the fins across the airflow and
   be held by its own mounting tabs or two M3 screws through the liner side walls
   into the element's frame holes (most 300 W elements have them). Never let the
   ceramic touch the liner directly; the element's own aluminum frame is the
   contact.

## Order of assembly

1. **Back plate** halves: join them at the lap (two M3 through the lap, nuts behind),
   then offer the assembled plate up to the printer, empty, to confirm the hole
   pattern and that the bed at Z max and the gantry clear it. Take it back off.
2. **Filter bay body** onto the back plate (6 x M3). Foam tape along the top edge of
   the bay where it meets the mid body.
3. **Mid body** onto the back plate. Mount the blower on its four M4 standoffs with
   the outlet pointing up through the slot into the heater plenum. Foam tape around
   the blower outlet flange.
4. **Electronics bay**: the standoff bosses are on the back plate, so fit the
   HLK-10M24, SSR carrier, MOSFET module, buck, fuse holder and terminal block to
   the plate before the mid body goes on, then close the mid body over them. Wire per `wiring.md` with the cover
   off. Route the three NTC leads: chamber NTC pokes into the filter plenum through
   the small hole at the bay floor; duct NTC and thermal fuse lead go up into the
   heater section through the grommet hole; the bed probe JST-XH sits in the slot on
   the lower front. Fit the PG7 grip in the side-wall hole and the cord last.
5. **Heater shell** over the liner: the blower discharges up through the mid-body
   roof into the shell cavity, which is the cold-side plenum around the liner; the
   liner takes air through the slot in its bottom wall. Screw the liner to the back
   plate through its slotted tabs (the slots allow thermal expansion), fit the shell
   over it with the 8 mm gap all round, then screw the slotted outlet plate through
   the liner lips into the four shell bosses. Strap the 130 C thermal fuse to the liner's top face with
   its tab and a dab of thermal paste, the duct NTC ring lug on the outer side face
   near the outlet end, the PE ring lug on the other side.
6. Plug the PTC into its two spade terminals, the blower into its JST-XH, the LED
   into its header. Fit the electronics cover.
7. Fill both carbon cartridges, screw the lids, slide them in, then the HEPA cells
   (two per bay, side by side), then the retainers, then snap the grilles on.
8. Antenna: stick the u.FL antenna on the inside of the electronics cover, as far
   from the liner and the back plate as it goes.

## Fitting to the U1

1. Route the cord up the rear wall, through the Sterilite cover grommet, out to the
   outlet. Leave a service loop inside so the cover can be lifted.
2. Run the bed probe lead from the unit's lower front along the rear wall and under
   the bed. Clip it to the existing bed cable route so bed travel cannot pinch it.
   Check it at Z max and Z min by hand before the first homing.
3. Mount the unit on its four fasteners, foam tape between the back plate and the
   wall. Confirm by hand that the toolhead dock, the cable chain, and the bed at
   every Z clear the unit by at least 10 mm.
4. Bring-up: `bringup.md`, in order. Do not skip the GFCI step.

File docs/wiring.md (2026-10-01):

# Wiring

Electrical design for U1 Breath: a 120 V, 300 W PTC chamber heater and HEPA/carbon filter for
the Snapmaker U1, controlled by a Seeed XIAO ESP32-C3 running the DragonBreath firmware fork.
Part numbers and ratings are in [`bom.md`](bom.md). The schematic below is the reference drawing;
this page is the text version of the same circuit.

U1 Breath wiring schematic

`wiring.svg` is a hand-drawn schematic, not a board layout. Boxes are parts, lines are wires, and
the colours follow the conventions in [Wire gauge and colours](#wire-gauge-and-colours).
The XIAO is drawn as a symbol with its pins grouped by function; the physical pin order is in the
table below.

## Read this first: mains safety rules

The heater side of this unit is 120 V mains. It will hurt or kill you if you are careless.

1. Every mains conductor (cord, terminal block, fuse, SSR load side, thermal fuse, thermal
   protector, PTC leads, HLK-10M24 input) stays inside the electronics compartment, under the
   cover. Nothing at mains potential is reachable with the cover on.
2. Crimp, never twist. Every mains joint is a crimped spade or ring terminal, or a ferrule in
   the lever terminal block. No twisted-and-taped joints, no solder-only joints on mains.
3. PE (protective earth, the green cord conductor) is bonded to the aluminium heater liner
   with a ring terminal under its own M3 screw, and to the back plate ground point if the back
   plate carries any metal. Test for continuity (under 0.1 ohm) from the cord plug's earth pin
   to the liner before the first power-up.
4. The 5 A slow-blow fuse comes first. It is the first thing after the terminal block on L;
   everything downstream (SSR, heater, HLK-10M24) is behind it.
5. The 130 C thermal fuse and the PTC's bundled 150 C thermal protector are in series with
   the element. They are the hardware backstop if the firmware, SSR, or blower fails. Never
   bypass them, and replace a blown thermal fuse with the same rating.
6. Never run the heater with the blower unplugged. A 300 W PTC with no airflow will trip the
   protector, then the thermal fuse, and can damage the shell. The firmware always runs the
   blower while heating and the duct sensor folds the heater back if the liner overheats, but
   there is no tachometer: a stalled blower is caught thermally, not electrically.
7. Test with a GFCI outlet on the first power-up, and ideally keep using one.
8. Unplug before opening. The SSR leaks a little current even when off, and the HLK-10M24
   input capacitor holds a charge for a few seconds after unplugging. Pull the plug, count to
   ten, then open the cover.

## Connector and pin table

Seeed XIAO ESP32-C3, viewed from the top with the USB-C connector up. Left column D0 to D6 top
to bottom, right column 5V, GND, 3V3, D10, D9, D8, D7 top to bottom.

| XIAO pin | GPIO | Function | Goes to |
|---|---|---|---|
| D0 | GPIO2 (ADC1_CH2) | Chamber air temperature, ADC | Divider node: 100 kOhm to 3V3, chamber NTC (glass bead, intake plenum) to GND, 100 nF to GND |
| D1 | GPIO3 (ADC1_CH3) | Duct / PTC temperature, ADC | Divider node: 100 kOhm to 3V3, duct NTC (M3 ring lug on the liner's outer side face) to GND, 100 nF to GND |
| D2 | GPIO4 (ADC1_CH4) | Bed probe temperature, ADC | Divider node: 100 kOhm to 3V3, bed NTC (M3 ring lug under the bed, 600 mm lead, JST-XH 2-pin) to GND, 100 nF to GND |
| D3 | GPIO5 | Unused | Not connected |
| D4 | GPIO6 | Heater SSR drive, digital out | 100 ohm series resistor, then SSR control + ; SSR control - to GND |
| D5 | GPIO7 | Blower PWM, 25 kHz | MOSFET module SIG |
| D6 | GPIO21 | Console UART TX | Optional 3-pin header (TX, RX, GND) |
| D7 | GPIO20 | Console UART RX | Optional 3-pin header (TX, RX, GND) |
| D8 | GPIO8 | Unused | Not connected (strapping pin, leave free) |
| D9 | GPIO9 | BOOT button (on board) | Nothing external. Tap = arm AUTO / master OFF, hold 2 s = panic-off, hold 10 s = factory reset |
| D10 | GPIO10 | Status LED data | 330 ohm series resistor, then WS2812B DIN |
| 5V | - | Board supply in | MP1584 buck output, set to 5.0 V |
| 3V3 | - | 3.3 V out (board regulator) | Top of the three NTC dividers |
| GND | - | Common ground | HLK-10M24 GND, buck GND, MOSFET GND, SSR control -, LED GND, NTC and capacitor returns |
| USB-C | - | Flashing and serial | Host computer only; not used in the installed unit |

Other connectors on the unit:

| Connector | Pins | Purpose |
|---|---|---|
| IEC-style bare cord through PG7 cord grip | L (black), N (white), PE (green) | Mains in |
| JST-XH 2-pin, blower | + (red), - (black) | 24 V blower, polarised |
| JST-XH 2-pin, bed probe | NTC, NTC (no polarity) | 600 mm silicone lead to the bed ring lug |
| 3-pin 2.54 mm header (optional) | TX, RX, GND | Console UART, 3.3 V logic |

## Mains path (120 V)

In order, from the wall to the heater. Everything on this list lives in the electronics
compartment and is 18 AWG silicone wire with crimped spade or ring terminals (ferrules in the
terminal block).

1. 3-conductor 18 AWG SJT cord enters through the PG7 cord grip in the compartment wall.
2. Cord conductors land in the 3-position lever terminal block (Wago 221-413 or equivalent):
   L (black), N (white), PE (green). This block is the only place the cord terminates.
3. PE (green) leaves the block as 18 AWG green wire with a ring terminal under a dedicated
   M3 screw and star washer on the aluminium heater liner. This bonds the liner. If the back
   plate carries any metal, a second green wire runs from the same block position to a ring
   terminal on the back plate ground point. PE does nothing else and is never switched or fused.
4. L leaves the block to the 5 x 20 mm fuse holder with a T5A 250 V slow-blow fuse.
5. Fuse output goes to the SSR load terminal 1 (10 A zero-cross PCB SSR, 3 to 32 V DC input).
   The same fused-L node also feeds the HLK-10M24 L input (step 10).
6. SSR load terminal 2 goes to the 130 C thermal fuse (Microtemp G4A01130 class), which is
   strapped to the liner so it reads liner temperature.
7. Thermal fuse output goes to the PTC element's bundled normally-closed 150 C thermal
   protector.
8. The protector feeds the PTC element itself (110 V nameplate, 300 W, insulated).
9. The PTC's other lead returns to N at the terminal block.
10. The HLK-10M24 AC-DC module (24 V, 0.42 A) takes L from the fused node (after the fuse,
    before the SSR) and N from the terminal block. It is always on when the cord is plugged in,
    so the controller and blower run whether or not the heater is on.

Heater current is about 2.5 A at 120 V with a short inrush of roughly 2x. The 5 A slow-blow fuse
protects the wiring, not the element; the thermal fuse and protector protect the element and
the shell.

## Low-voltage path (24 V and 5 V)

- HLK-10M24 +24 V out feeds the blower + (red) and the MP1584 mini buck IN+.
- The buck is set to 5.0 V before it is connected. Buck OUT+ goes to the XIAO 5V pin.
- All grounds are common: HLK-10M24 GND, buck IN-/OUT-, XIAO GND, MOSFET module GND,
  SSR control -, LED GND, and every sensor return.
- Blower - (black) goes to the MOSFET module OUT-. The module's V+ is tied to 24 V if the
  module needs it (the D4184 module does; a bare AO3400 breakout does not). The module's
  SIG input comes from XIAO D5 (GPIO7), driven with 25 kHz PWM. Low-side switching, so the
  blower's + lead is always at 24 V and only the return is chopped.
- SSR control: XIAO D4 (GPIO6) through a 100 ohm series resistor to SSR control +. SSR control
  - to GND. The SSR input is rated 3 to 32 V DC, so the 3.3 V GPIO drives it directly; the
  resistor limits the gate current and protects the GPIO if the SSR input ever shorts.
- WS2812B status LED: 5 V and GND from the 5 V rail with a 100 uF electrolytic across the LED
  supply pins, DIN from XIAO D10 (GPIO10) through a 330 ohm series resistor, mounted close to
  the LED.
- UART console (optional): D6 (GPIO21) is TX and D7 (GPIO20) is RX on a 3-pin header. The
  XIAO's own USB-C port is used for flashing and gives the same console, so the header is
  only there if you want a logic-analyser or serial-adapter hookup with the cover on.
- BOOT button (GPIO9): tap = arm AUTO or master OFF, hold 2 s = panic-off, hold 10 s = factory reset (erases WiFi and settings).
- Unused: D3 (GPIO5) and D8 (GPIO8). Leave them unconnected; GPIO8 is a strapping pin.

## Sensor dividers

Three identical dividers, one per NTC. Each NTC is 100K at 25 C, Beta 3950, 1 percent. The
fixed resistor is 100 kOhm 1 percent, so the divider is centred on 25 C and reads well across
the 20 to 80 C range the firmware cares about.

Each divider: 3V3 to the 100 kOhm fixed resistor, the far end of the resistor is the ADC node
that goes to the XIAO pin, the NTC goes from that node to GND, and a 100 nF ceramic capacitor
sits from the node to GND to filter blower and SSR noise. The capacitor and resistor go on the
small perfboard next to the XIAO, not out at the sensor.

```
 3V3 ----[ 100k 1% ]----+---- ADC pin (D0 / D1 / D2)
                         |
                      [ NTC ]   100K, B3950
                         |
                         +---- 100 nF ---- GND
                         |
                        GND
```

| Sensor | NTC type | Location | ADC pin |
|---|---|---|---|
| Chamber air | Glass bead | In the intake plenum, in the airstream, not touching the liner | D0 (GPIO2, ADC1_CH2) |
| Duct / PTC | M3 ring lug | On the liner's outer side face, under its own M3 screw, Kapton under the lug | D1 (GPIO3, ADC1_CH3) |
| Bed probe | M3 ring lug | Under the printer bed, 600 mm 2-conductor silicone lead to the JST-XH 2-pin on the unit | D2 (GPIO4, ADC1_CH4) |

The ring-lug NTCs are electrically isolated from their lugs, but still put Kapton between the
lug and the liner so the sensor lead cannot pick up PE as a return path.

## Wire gauge and colours

| Circuit | Gauge | Colour | Termination |
|---|---|---|---|
| Mains L | 18 AWG silicone, 200 C | Red (black in the cord) | Insulated crimp spade/ring, ferrule in the block |
| Mains N | 18 AWG silicone | Blue (white in the cord) | Insulated crimp spade/ring, ferrule in the block |
| PE | 18 AWG silicone | Green or green/yellow | Ring terminal, M3 screw and star washer |
| PTC and thermal fuse leads | 18 AWG silicone, glass-fibre sleeve | As supplied (bundle in glass sleeve) | Crimp, heat-shrink over the crimp |
| 24 V | 22 AWG silicone | Orange (+), black (-) | Soldered to modules, JST-XH to the blower |
| 5 V | 22 AWG silicone | Purple (+), black (-) | Soldered |
| 3.3 V sensor supply | 24 AWG silicone | Pink or white | Soldered on the perfboard |
| Signals (SSR drive, PWM, LED DIN, UART) | 24 AWG silicone | Grey, yellow for PWM if you want to tell them apart | Soldered, header |
| NTC leads | 24 AWG silicone, 2-conductor for the bed probe | White/white | Soldered on the perfboard, JST-XH for the bed probe |

The same colours are used in `wiring.svg`: red L, blue N, green PE, orange 24 V, purple 5 V,
pink 3.3 V, black GND, grey signals.

Keep the mains bundle and the low-voltage bundle on opposite sides of the compartment; the
SSR control leads cross to the SSR, nothing else does. Heat-shrink every crimp on the PTC and
thermal fuse leads, and sleeve the PTC leads in glass fibre where they pass the liner.

## First power-up checklist

1. Cover off, cord unplugged. Continuity from the plug's earth pin to the liner and back plate
   is under 0.1 ohm. No continuity from L or N to PE or to the liner.
2. Buck trimmed to 5.0 V with the XIAO disconnected, then connected.
3. Blower plugged in, SSR control leads connected, heater leads connected.
4. Cover on. Plug into a GFCI outlet. The LED should come up within two seconds.
5. Confirm all three temperatures read room temperature in the console before enabling the
   heater for the first time.
6. First heat run with someone watching: the duct NTC should rise well before the chamber
   NTC, and the blower must be running the whole time.

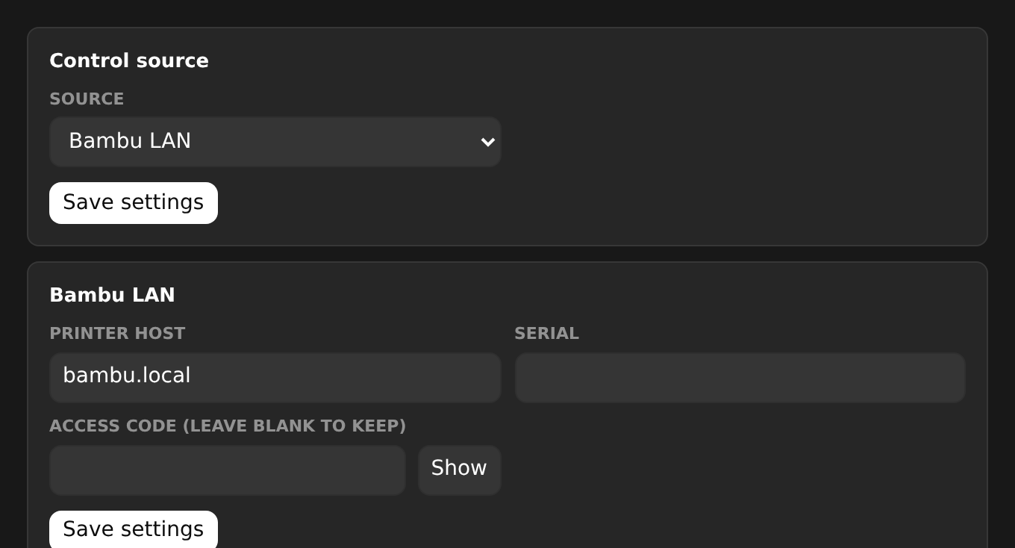
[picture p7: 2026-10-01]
firmware/dragonbreath/docs/screenshots/setup-bambu.png

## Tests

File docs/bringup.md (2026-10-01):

# Bring-up

Do this in order. Every step before "first heat" happens with the PTC unplugged
from the SSR.

## 0. Bench, no mains

1. Flash the firmware over the XIAO's USB-C (`firmware/README.md`). Open the serial
   monitor. Expect `board init: U1 Breath`, `pb_ntc init ok (Rref=100 kOhm)`,
   `pb_fan init: DC blower PWM on GPIO7`.
2. Power the XIAO from USB only. Plug in the three NTCs. Open the web UI calibration
   page (`/api/v2/calibration` or the Settings page): chamber, ptc and bed should
   read room temperature within a degree or two. Warm each one with a finger and
   watch it move. A reading of "open" means a swapped or broken divider.
3. Blower: from the web UI turn the filter on. It must spin at the 40 percent floor
   and at 100 percent. If it twitches but does not start, raise
   `PB_FAN_MIN_PERCENT` in `pb_board.h`.
4. LED: dim white idle, green when you arm AUTO, red blinking if you unplug a
   sensor while heating is armed.

## 1. Mains, heater still unplugged

1. Check continuity: PE pin of the plug to the liner, to the back plate if metal,
   and to nothing else. L and N to nothing on the chassis.
2. Plug into a GFCI outlet. The HLK should give 24.0 V, the buck 5.0 V. The XIAO
   boots on its own power and joins WiFi.
3. From the web UI set a manual target of 40 C. The SSR LED must light; a meter on
   the SSR output must show 120 V. Set target 0: it drops.

## 2. First heat

1. Plug the PTC in. Blower on, then target 45 C. The duct sensor should climb
   within 30 s. Watch for: smell of hot plastic (stop), the shell near the liner
   getting too hot to touch (stop), the fault LED.
2. Let it run to the target with the chamber open, then closed with the tote on.
   Log `sensors.ptc.temperature_c` at steady state with the chamber at 60 C.

## 3. Set the duct foldback

The upstream firmware trips a latching fault at 105 C on the duct sensor and folds
power back (soft cut) at `fb_cut`, default 102 C. Your duct sensor sits on the liner
wall, not on the Panda's element, so:

- If the steady-state duct reading is **below 85 C**: leave `fb_cut` at auto.
- If it is **85 to 95 C**: set `fb_cut` to about 8 C above the reading (web UI
  Settings, or `POST /settings?fb_cut=98`). The foldback then only acts when the
  blower stalls or a filter clogs, which is what it is for.
- If it is **above 95 C**: move the ring-lug NTC 20 mm further toward the outlet
  end of the liner (cooler), or add the second liner screw as a thermal path to
  the back plate. Do not raise the hard cutoff in firmware.

Confirm the blower-failure trip once: unplug the blower with the heater at 60 C.
The duct reading must climb and the unit must latch a fault (red blinking, heater
off) before the shell gets hot. Clear with the web UI or `DRAGONBREATH_RESET`.

## 4. Bed probe

1. Stick the probe under the bed plate (`measurements.md`). Heat the bed to 60 C
   from the printer; the `bed` sensor should follow within a few degrees and a
   minute of lag. Use the calibration offset (max 5 C) to trim it.
2. Arm AUTO. Set the bed to 100 C: the unit must engage at 90 C on the probe and
   heat to the AUTO target. Drop the bed to 50 C: it must release once the probe
   reads below 70 C and keep the blower on until the duct cools.
3. Set the bed to 55 C: no heat, but the blower runs (filtration band at 45 C).

## 5. Klipper

1. Static DHCP lease for the unit. Enable DragonBreath in the printer's Firmware
   Config with that IP (`klipper/README.md`).
2. In the printer console: `M141 S50`. The unit's web UI shows mode POWER_ON, owner
   `klipper`, and a lease countdown that keeps resetting. `M141 S0`: the unit
   returns to AUTO (if armed) or OFF.
3. Print an ABS calibration cube with `M191 S55` in the start G-code. Watch the
   U1's host temperature in Fluidd; if the mainboard passes 75 C, improve the
   mainboard cooling before longer prints.

## 6. Ongoing

- Carbon: swap when the smell returns (typically 100 to 150 h of ABS).
- HEPA: when the blower note rises or airflow at the outlet drops noticeably.
- Thermal fuse: if it ever opens, find the cause (blower, clogged filter, SSR
  failed shorted) before replacing it.

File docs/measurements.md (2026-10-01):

# Measurements only you can take

The CAD is parametric so that nothing here blocks the design, but each of these feeds a
value in `cad/u1breath/params.py` or `docs/bom.md`. Take them before printing.

| # | Measure | Feeds | Default assumed |
|---|---|---|---|
| 1 | Rear wall clear rectangle: width and height of flat wall below the toolhead dock and above the bed at max Z. Note wall material and thickness, and any existing holes or slots with their spacing. | `MOUNT_HOLES` list and `BACK_PLATE_*` in `params.py` | 273 x 175 mm free, slots on a 20 mm grid |
| 2 | Carbon pellet size (from the bag, or measure ten pellets). | `CARBON_MESH_PITCH` | 2 mm openings for 3 to 4 mm pellets |
| 3 | A bare aluminum spot on the underside of the bed plate for the probe, and a cable route to the rear wall that clears bed travel. | Bed probe lead length in the BOM | 600 mm silicone lead |
| 4 | The three outer dimensions of the 300 W PTC element you order (length, depth in the airflow direction, height). | `PTC_L`, `PTC_D`, `PTC_H` | 150 x 32 x 26 mm |
| 5 | Where on the Sterilite cover the cord grommet goes. | Cord length in the BOM | 1.8 m cord |

## How to measure the rear wall

1. Home the printer, then jog the bed to Z max and the gantry to Y max so you see the real
   envelope.
2. Measure from the bed plate top at Z max up to the lowest part of the toolhead dock or
   cable chain. That is the available height; subtract 10 mm for air.
3. Measure the flat width between the frame uprights or any ribs.
4. Photograph the wall and mark any pre-existing holes. If there are none, the back plate
   takes M3 or M4 through-holes with nuts behind the panel, or 3M VHB pads on a clean
   metal panel (the unit weighs under 900 g).

## Bed probe placement

The bed probe is a 100K 3950 NTC. A ring-lug style thermistor under an existing bed screw
is best; a glass bead held with Kapton and a dab of thermal epoxy on the aluminum plate is
fine. Keep it 20 mm or more from the silicone heater's wires and off the heater pad
itself, so it reads plate temperature, not heater wire temperature.

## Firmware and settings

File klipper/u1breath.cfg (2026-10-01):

# U1 Breath helper macros for Klipper on the Snapmaker U1 (paxx12 Extended Firmware).
#
# Prerequisite: enable "DragonBreath Chamber Heater" in Firmware Config
# (http://<printer-ip>/firmware-config/) with the unit's static IP. That generates
# extended/klipper/dragonbreath.cfg, which provides:
#   M141 S<C>              set chamber target (S0 = off)
#   M191 S<C>              set target and wait
#   DRAGONBREATH_RESET     clear a latched fault
#   SET_PIN PIN=dragonbreath_filter VALUE=1|0   blower only
# and exposes the unit as a heater_generic in Fluidd/Mainsail.
#
# Install: copy this file to /home/lava/printer_data/config/extended/klipper/ and
# add it through the Firmware Config "custom Klipper includes" option (or an
# [include] in extended2.cfg), then RESTART.

[gcode_macro CHAMBER_PREHEAT]
description: Heat the chamber for a material and wait. CHAMBER_PREHEAT MATERIAL=ABS, or CHAMBER_PREHEAT TEMP=55
gcode:
    {% set mat = params.MATERIAL|default('')|upper %}
    {% set table = {'ABS': 55, 'ASA': 55, 'PC': 60, 'PA': 55, 'NYLON': 55, 'PPS': 65,
                    'PETG': 0, 'PLA': 0, 'TPU': 0} %}
    {% set t = params.TEMP|default(table.get(mat, 0))|int %}
    {% if t > 0 %}
        RESPOND MSG="U1 Breath: chamber target {t}C ({mat if mat else 'manual'}), waiting"
        M191 S{t}
    {% else %}
        RESPOND MSG="U1 Breath: no chamber heat for {mat if mat else 'this material'}"
        M141 S0
    {% endif %}

[gcode_macro CHAMBER_SET]
description: Set the chamber target without waiting. CHAMBER_SET TEMP=55 (0 = off)
gcode:
    M141 S{params.TEMP|default(0)|int}

[gcode_macro CHAMBER_OFF]
description: Release the chamber heater. The unit returns to AUTO if it was armed.
gcode:
    M141 S0

[gcode_macro CHAMBER_FILTER]
description: Blower only, no heat. CHAMBER_FILTER ON=1 or ON=0
gcode:
    SET_PIN PIN=dragonbreath_filter VALUE={params.ON|default(1)|int}

# Call this from your PRINT_END (or the slicer's end G-code). The unit keeps the
# blower running on its own residual-heat purge until the duct and chamber cool.
[gcode_macro _U1BREATH_PRINT_END]
gcode:
    M141 S0

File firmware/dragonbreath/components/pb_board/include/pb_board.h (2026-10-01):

// SPDX-License-Identifier: MIT
// pb_board — single source of truth for Panda Breath V1.0.1 GPIO assignments.
//
// Hardware: BIGTREETECH Panda Breath V1.0.1, ESP32-C3-MINI-1-H4X, mains-powered
// PTC chamber heater + AC blower fan. Pinout reverse-engineered from the board
// and schematic (credit: Justin Hayes / klipper-esp32 RE). Values marked
// INFERRED should be continuity-tested before the first flash to real hardware.
#pragma once

#include "sdkconfig.h"
#include "driver/gpio.h"
#include "hal/adc_types.h"

#ifdef CONFIG_PB_BOARD_U1BREATH
// ======== U1 Breath — Seeed XIAO ESP32-C3 carrier =========================
// Chamber heater + HEPA/carbon filter for the Snapmaker U1. All pins below are
// XIAO header pins; GPIO18/19 (native USB) stay free for flashing/console.
#define PB_GPIO_RELAY        GPIO_NUM_6    // XIAO D4 -> SSR+ (100R series), SSR- -> GND
#define PB_GPIO_FAN_PWM      GPIO_NUM_7    // XIAO D5 -> MOSFET module SIG, 25 kHz PWM
#define PB_FAN_MIN_PERCENT   40            // 7530 DC blower reliable-start floor
#define PB_GPIO_NTC_CHAMBER  GPIO_NUM_2    // XIAO D0, ADC1_CH2: chamber air (intake plenum)
#define PB_GPIO_NTC_PTC      GPIO_NUM_3    // XIAO D1, ADC1_CH3: heater duct liner wall
#define PB_GPIO_NTC_BED      GPIO_NUM_4    // XIAO D2, ADC1_CH4: printer bed underside probe
#define PB_ADC_UNIT          ADC_UNIT_1
#define PB_ADC_CH_CHAMBER    ADC_CHANNEL_2
#define PB_ADC_CH_PTC        ADC_CHANNEL_3
#define PB_ADC_CH_BED        ADC_CHANNEL_4
#define PB_BOARD_RREF_KOHM   100           // fixed 100k 1% low-side dividers, no strap
#define PB_GPIO_LED_WS2812   GPIO_NUM_10   // XIAO D10 -> WS2812 DIN (330R series)
#define PB_GPIO_BTN_POWER    GPIO_NUM_9    // XIAO BOOT button (strap: HIGH at reset)
#define PB_GPIO_BTN_AUTO     GPIO_NUM_NC   // single-button board
#define PB_GPIO_BTN_ON       GPIO_NUM_NC
#define PB_GPIO_BTN_DRY      GPIO_NUM_NC
#define PB_GPIO_UART_TX      GPIO_NUM_21   // XIAO D6 (optional UART console header)
#define PB_GPIO_UART_RX      GPIO_NUM_20   // XIAO D7
#else
// ======== BIGTREETECH Panda Breath V1.0 / V1.0.1 ==========================

// -------- Heater (safety-critical) -----------------------------------------
// GPIO18 -> Q3 NPN -> MGR-GJ-5-L solid-state relay coil -> PTC heater AC switch.
// Simple on/off (the SSR is zero-cross DC-controlled; no phase control here).
#define PB_GPIO_RELAY        GPIO_NUM_18   // RLY_MOSFET (INFERRED, pad 26)

// -------- Fan (AC, phase-angle TRIAC) --------------------------------------
// GPIO3 gate -> MOC3021 random-phase opto-triac -> BT136-800E TRIAC -> FAN.
// Synced to the zero-cross detector (MB6S bridge + TLP785 opto) on GPIO7.
#define PB_GPIO_FAN_GATE     GPIO_NUM_3    // TRIAC gate (CONFIRMED, IO03)
#define PB_GPIO_ZERO_CROSS   GPIO_NUM_7    // ZCD input  (CONFIRMED, IO07)
                                           // ZCD ISR only — NOT a button (the old
                                           // "K1 button on GPIO7" note was wrong;
                                           // buttons are on 2/8/9/10, see below).

// -------- Thermistors (ADC1) ------------------------------------------------
// Both NTCs are read on ADC1 via adc_oneshot in the stock firmware.
#define PB_GPIO_NTC_CHAMBER  GPIO_NUM_0    // TH0 (INFERRED, pad 12)
#define PB_GPIO_NTC_PTC      GPIO_NUM_1    // TH1 (INFERRED, pad 13)
#define PB_ADC_UNIT          ADC_UNIT_1
#define PB_ADC_CH_CHAMBER    ADC_CHANNEL_0 // GPIO0 = ADC1_CH0
#define PB_ADC_CH_PTC        ADC_CHANNEL_1 // GPIO1 = ADC1_CH1

// -------- NTC divider strap -------------------------------------------------
// Read once at boot: selects the fixed series resistor value used to solve for
// the thermistor resistance (see pb_ntc). level 0 -> 82 kOhm, level 1 -> 33 kOhm.
#define PB_GPIO_RREF_STRAP   GPIO_NUM_19

// -------- Front-panel LEDs (active-high, direct push-pull; NOT a matrix) -----
// Confirmed by stock-firmware RE (byte-identical across stock 1.0.1-1.0.4).
// K1/K2/K3 are the three mode LEDs; the "Power" LED is on GPIO21 — which is also
// the UART0 console TX pin, so it is only driven when CONFIG_PB_POWER_LED is set
// (release builds); otherwise GPIO21 stays the serial console. See pb_leds.
#define PB_GPIO_LED_K1       GPIO_NUM_6    // "Auto"
#define PB_GPIO_LED_K2       GPIO_NUM_5    // "On"
#define PB_GPIO_LED_K3       GPIO_NUM_4    // "Dry"
#define PB_GPIO_LED_POWER    GPIO_NUM_21   // "Power" (shared with UART0-TX)
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

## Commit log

2026-10-01 Add U1 Breath project scaffold: README, BOM, measurements
    Claude-Session: https://claude.ai/code/session_015T6pPyW2MyNs8UR5edk4vM
2026-10-01 Squashed 'firmware/dragonbreath/' content from commit f311a22
    git-subtree-dir: firmware/dragonbreath
    git-subtree-split: f311a22c39a3e3aef92d10f0f6c3f2d5d63e02b9
    [dragonbreath-logo-plaque.3mf, partitions.csv]
2026-10-01 Add design, wiring, assembly and bring-up docs, Klipper macros, CI workflows
    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
    [u1breath.cfg]
2026-10-01 firmware: add u1breath board profile to DragonBreath
    - CONFIG_PB_BOARD_U1BREATH Kconfig choice; Panda build unchanged
    - XIAO ESP32-C3 pin map: SSR GPIO6, blower PWM GPIO7, NTCs GPIO2/3/4,
    WS2812 GPIO10, BOOT button GPIO9, native USB console
    - pb_ntc: 3 channels, 100K/3950 Beta model, fixed 100k divider, bed offset
    - pb_fan: LEDC 25 kHz PWM backend for the 24 V DC blower
    - pb_leds: single WS2812 status pixel backend
    - pb_buttons: single-button board, 10 s hold = factory reset
    - pb_policy: local bed-probe AUTO trigger with hysteresis (90/70 C),
    probe feeds the filtration band, Klipper OFF restores AUTO, config API
    - pb_httpd: sensors.bed, environment.probe_heat, params/settings/
    calibrat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
    [pb_board.c, pb_board.h, pb_buttons.c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]
2026-10-01 firmware: keep the ADC state shared between the Beta and table NTC models
    The U1 Breath conversion guard in pb_ntc.c had swallowed the ADC handle,
    channel table and filter state into the Panda-only branch, so the
    u1breath build failed with undeclared statics. Only the conversion
    function and the R/T table are board-specific now.
    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
    [pb_ntc.c]
2026-10-01 firmware: require the managed led_strip component by its registered name
    ESP-IDF registers component-manager dependencies as <namespace>__<name>,
    so pb_leds must PRIV_REQUIRE espressif__led_strip for led_strip.h to
    resolve in the u1breath build.
    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
2026-10-01 firmware: vendor led_strip and fix the pb_leds requirement; quieter CI
    - Vendor espressif led_strip 3.0.3 (Apache-2.0) into components/led_strip so
    neither CI nor local builds depend on the Espressif component registry.
    - pb_leds PRIV_REQUIRES led_strip unconditionally: ESP-IDF resolves component
    requirements before sdkconfig is loaded, so a CONFIG_-gated requirement was
    silently empty (the cause of the led_strip.h failures on CI).
    - Workflows run on pull_request only (a push to a PR branch was running every
    job twice), and the CAD job skips cleanly while cad/build.py is absent.
    Verified: u1breath and panda images build locally with ESP-IDF v5.3.5.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
2026-10-01 cad: CadQuery parametric model, exporter, and envelope tests
    Parts: two-piece back plate, filter bay body, intake grilles, carbon
    cartridges and lids, HEPA retainers, mid body, electronics cover, heater
    shell, aluminum liner (STEP + DXF flat pattern with slotted outlet plate),
    plus keep-out reference volumes. build.py exports STL/STEP/DXF and
    layout/exploded SVGs; 9 pytest checks cover the 273x175x55 envelope,
    256 mm build volume, the 8 mm hot gap around the liner, and keep-outs.
    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
2026-10-28 Add v2 PRD for the Fusion rebuild (#4)
    docs/prd-v2.md briefs a local Fusion session: same BOM and firmware, a
    one-piece chassis, a ducted heater housing with a sealed lead compartment,
    a walled mains area, filter drawers, a parameter table, and acceptance
    checks to run in Fusion. It maps every v1 audit defect to the requirement
    that prevents it. Two independent reviews (feasibility, safety) were
    resolved and every budget recomputed. CLAUDE.md points future sessions at it.
    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
